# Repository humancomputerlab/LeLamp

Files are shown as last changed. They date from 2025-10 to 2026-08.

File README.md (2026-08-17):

# LeLamp

LeLamp Banner

An open source robot lamp based on [Apple's Elegnt](https://machinelearning.apple.com/research/elegnt-expressive-functional-movement), made by [Human Computer Lab](https://www.humancomputerlab.com/)

**UPDATE:** We are working on a closed-source version that will release end of 2027. You can also follow along on [TikTok](https://www.tiktok.com/@itslelamp?lang=en), [Instagram] (https://www.instagram.com/itslelamp/), [YouTube](https://www.youtube.com/@itslelamp), [LinkedIn](https://www.linkedin.com/company/humancomputerlab/?viewAsMember=true) and [X](https://x.com/humancomplab) for behind-the-scenes + updates.

[LeLamp Website](https://www.lelamp.com/)

## Overview

LeLamp in real life

**Build specs:** ~$260 cost | 8-12 hours | Intermediate skill level

LeLamp is an expressive robot lamp featuring:

- 🎭 **5-axis articulated movement** with servo motors
- 📸 **Computer vision** via Pi Camera
- 🎤 **Audio interaction** with microphone and speaker
- 💡 **LED expressions** with 24 programmable LEDs
- 🎮 **Record & replay** custom movements

## Build Guide

**Start here:** [Prerequisites & Planning](./docs/0.%20Prerequisites.md)

### Complete Build Process

1. [📋 Prerequisites & Planning](./docs/0.%20Prerequisites.md) - Skills, tools, and BOM
2. [🔧 Components & 3D Parts](./docs/1.%203D%20Print.md) - Components and 3D Printed Models
3. [🎯 Lamp Assembly](./docs/3.%20LeLamp%20Assembly.md) - Mechanical and electrical assembly
4. [🏗️ Lamp Setup](./docs/4.%20LeLamp%20Setup.md) - Runtime Setup
5. [🎮 Lamp Control](./docs/5.%20LeLamp%20Control.md) - Controlling LeLamp
6. [🔍 Common Issues](./docs/6.%20Common%20Issues.md) - Common issues and solutions

### Quick Reference

- **Bill of Materials**: [Complete component list with suppliers](./docs/0.%20Prerequisites.md#bill-of-materials)
- **3D Print Files**: Available in `/3D/` directory ([OnShape CAD](https://cad.onshape.com/documents/16c9706360b5ad34f9c8db49/w/2edfa54c83253c120fbc9e58/e/a7196194821d9cfe2842a44a))
- **Order the Kit**: [Register interest here](https://docs.google.com/forms/d/e/1FAIpQLSfOXO2q_I2LKqYE0LoPN8VtrpKWrvJ1OkRAiS1iBFML1eqoGw/viewform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)
- **Software Control**: [LeLamp Runtime Repository](https://github.com/humancomputerlab/lelamp_runtime)

## Project Status

⚠️ **Early Development** - This project is actively being developed. We published our progress early to encourage community feedback and iteration. We are working on a closed-source version that will release in 2026. You can also follow along on TikTok, Instagram, YouTube, LinkedIn and X for behind-the-scenes + updates.

## Community & Support

### Getting Help

- **Start here**: [Troubleshooting Guide](./docs/6.%20Troubleshooting.md) for common issues
- **Discord**: [Join our community](https://discord.gg/727JXBt8Zt) for real-time help and discussions
- **GitHub Issues**: [Report bugs or ask questions](https://github.com/humancomputerlab/le_lamp/issues)

### Contributing

We welcome contributions:

- 🐛 Bug reports and fixes
- 📖 Documentation improvements
- 🔧 Design enhancements
- 🌍 Regional supplier information
- 📸 Build photos and videos

Please check existing issues before creating new ones.

## Maintainers
Maintained by [Human Computer Lab](https://www.humancomputerlab.com).

## Acknowledgments & Sponsors
See [CONTRIBUTORS.md](./CONTRIBUTORS.md) for contributors and their roles.  
See [SPONSORS.md](./SPONSORS.md) for sponsor thanks and how to support the project.

## License

This project is licensed under the GNU General Public License v3.0 - see the [LICENSE](LICENSE) file for details.

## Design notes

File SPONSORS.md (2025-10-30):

Biggest thanks to Jennie and Lily at Seeed Studio for sponsoring the SO-101 Arm Kit for early developments of LeLamp.

Buy an SO-101 Arm Kit today on [SeeedStudio](https://www.seeedstudio.com/SO-ARM101-Low-Cost-AI-Arm-Kit-p-6426.html).

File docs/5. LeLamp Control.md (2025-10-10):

# Lamp Control

**⏱️ Estimated time:** 30 minutes  
**🔧 Required tools:** Computer with LeLamp runtime  
**📦 Required:** Fully assembled LeLamp with working head and body

For complete lamp control documentation, refer to the [**LeLamp Runtime's GitHub**](https://github.com/humancomputerlab/lelamp_runtime).

To follow this tutorial, ssh into your LeLamp and cd into `lelamp_runtime`. This was covered in the previous tutorial.

In commands below, remember to replace the name after `--id` to be your lamp name that you have used in previous section.

## Calibration

Before recording and replaying movements on the lamp, you need to calibrate:

```bash
sudo uv run -m lelamp.calibrate --id your_lamp_name --port your_port
```

The calibration script will run calibration twice, once for the lamp as a follower and once for the lamp as the leader. Follow the step outlined inside the CLI.

The script will mention you to put LeLamp into its zero position. The zero position is can be view in 3D [here](https://cad.onshape.com/documents/16c9706360b5ad34f9c8db49/w/2edfa54c83253c120fbc9e58/e/9bd935d578a9cbc77b5d66b3).

After putting LeLamp into its zero position, rotate each joint fully except for the lamp base motor (first motor on the base) or the lamp head motor (second motor from lamp head). **⚠️ Important: Do not fully rotate the lamp base or lamp head during calibration — this applies specifically to the two yaw servos. When setting them to their zero position, only rotate each servo about 90° clockwise and 90° counterclockwise from the center position. Rotating beyond this range may damage the servos or misalign the calibration.**

## Record and replay movements

To record movement, run the following command in runtime:

```bash
sudo uv run -m lelamp.record --id your_lamp_name --port your_port --name rotation
```

While recording movement, you can end and save the recording by holding `CTRL + C`.

To replay movement, run the following command in runtime:

```bash
sudo uv run -m lelamp.replay --id your_lamp_name --port your_port --name rotation
```

To list all recorded movements, run the following command in runtime:

```bash
sudo uv run -m lelamp.list_recordings --id your_lamp_name
```

## Final System Testing

After completing your LeLamp build, perform these final tests:

### Full System Integration Test

```bash
# Test all servo movements
sudo uv run -m lelamp.test.test_motors --id your_lamp_name --port your_port

# Test head components
sudo uv run -m lelamp.test.test_rgb     # LED ring
uv run -m lelamp.test.test_audio        # Audio I/O
libcamera-hello --timeout 2000         # Camera
```

### Record Your First Movement

1. **Position LeLamp** in a safe working area with full range of motion
2. **Record a simple movement** to test the system
3. **Replay the movement** to verify accuracy
4. **Save successful recordings** for future use

## Congratulations! 🎉

You have successfully built your LeLamp! Your robot lamp should now be capable of:

- ✅ Expressive movement through 5 degrees of freedom
- ✅ Visual interaction via camera
- ✅ Audio input/output for voice interaction
- ✅ Programmable LED expressions
- ✅ Recording and replaying custom movements

## Next Steps

- **Explore the runtime**: Check out advanced features in the [LeLamp Runtime repository](https://github.com/humancomputerlab/lelamp_runtime)
- **Join the community**: Share your build on [Discord](https://discord.gg/4hmNW3Ep)
- **Contribute back**: Help improve documentation or share build photos
- **Report issues**: Use [GitHub Issues](https://github.com/humancomputerlab/le_lamp/issues) for bugs or suggestions

---

**Previous**: [LeLamp Setup](./4.%20LeLamp%20Setup.md) | **Troubleshooting**: [Common Issues](./6.%20Common%20Issues.md)

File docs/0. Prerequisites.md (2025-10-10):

# Prerequisites for Building LeLamp

Before starting your LeLamp build, ensure you have the necessary skills, tools, and time to complete this project successfully.

## Skill Level Requirements

**Intermediate to Advanced** - This project requires:

- **Electronics experience**: Soldering, basic circuit understanding, component identification
- **3D printing knowledge**: Printer operation, material selection, post-processing
- **Software comfort**: Command line usage, SSH, basic Linux administration
- **Mechanical assembly**: Precision work with small components, heat inserts, servo mounting

**Estimated build time**: 8-12 hours over 2-3 days

## Required Tools

### Electronics Tools

- Soldering iron (temperature controlled, 15-25W)
- Solder (60/40 rosin core, 0.6-0.8mm)
- Wire strippers
- Small screwdrivers (Phillips #0, #1, flathead 2-3mm)
- Multimeter for continuity testing
- Anti-static wrist strap (recommended)

### Mechanical Tools

- Heat insert soldering iron tip OR dedicated heat insert tool
- M2 and M3 Allen keys/hex drivers
- Small pliers (needle nose)
- Wire cutters/flush cutters
- Digital calipers (for verification)

### 3D Printing Requirements

- **Printer bed size**: Minimum 200x200x150mm
- **Materials**: PLA+ recommended (PETG acceptable)
- **Layer height**: 0.2mm standard, 0.15mm for critical parts
- **Infill**: 20% minimum, 30% for structural components
- **Supports**: Required for some parts (see individual STL notes)

## Safety Warnings

⚠️ **ELECTRICAL SAFETY**

- Always disconnect power when making connections
- Use proper ESD precautions when handling Pi and servo driver
- Main power supply is 5V - verify correct voltage before connection
- Double-check polarity before powering on

⚠️ **MECHANICAL SAFETY**

- Heat inserts reach 200°C+ - use appropriate tools
- Servo horns under tension can snap - wear eye protection
- Small parts present choking hazard

## Bill of Materials

Bill of materials for LeLamp can be found [here](https://docs.google.com/spreadsheets/d/1C50qqSxJjCHEnh6j_Dcfx8JzyLlGobKSOYA0ePJUDVk/edit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).

Note: The links inside the BOM are reference only. You don't need to buy from those links. You should find the best deals in your region if possible.

**Total estimated cost (United States): $310.64 USD**

## Required External Resources

Before starting, ensure you have access to:

- **3D Printer** or printing service
- **Computer** for Pi setup and servo configuration
- **WiFi network** for Pi connectivity
- **LeLamp Runtime Repository**: https://github.com/humancomputerlab/lelamp_runtime

## Time Planning

### Phase 1: Preparation (2-3 hours)

- Download and review all documentation
- Source all components
- 3D print all parts
- Set up software environment

### Phase 2: Electronics Prep (2-3 hours)

- Test all components individually
- Solder headers and connectors
- Set up Raspberry Pi OS
- Configure servo IDs

### Phase 3: Assembly (4-6 hours)

- Install heat inserts
- Mount servos in 3D printed parts
- Route wiring through body
- Assemble head components
- Final integration and testing

## Pre-Build Checklist

- [ ] All components sourced and verified working
- [ ] 3D parts printed and post-processed
- [ ] Tools and workspace prepared
- [ ] Software downloaded and accounts created
- [ ] Safety equipment ready
- [ ] Adequate time allocated (don't rush!)

## Getting Help

If you encounter issues:

- **Discord Community**: https://discord.gg/4hmNW3Ep
- **GitHub Issues**: Report bugs and ask questions
- **Documentation**: Always check troubleshooting section first

---

**Next Step**: [1. 3D Print LeLamp](./1.%203D%20Print.md)

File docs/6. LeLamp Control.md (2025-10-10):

# Lamp Control

**⏱️ Estimated time:** 30 minutes  
**🔧 Required tools:** Computer with LeLamp runtime  
**📦 Required:** Fully assembled LeLamp with working head and body

For complete lamp control documentation, refer to the [**LeLamp Runtime's GitHub**](https://github.com/humancomputerlab/lelamp_runtime).

To follow this tutorial, ssh into your LeLamp and cd into `lelamp_runtime`. This was covered in the previous tutorial

## Calibration

Before recording and replaying movements on the lamp, you need to calibrate:

```bash
sudo uv run -m lelamp.calibrate --id lelamp --port /dev/tty.usbmodem5A680114681
```

The calibration script will run calibration twice, once for the lamp as a follower and once for the lamp as the leader. Follow the step outlined inside the CLI.

The script will mention you to put LeLamp into its zero position. The zero position is can be view in 3D [here](https://cad.onshape.com/documents/16c9706360b5ad34f9c8db49/w/2edfa54c83253c120fbc9e58/e/9bd935d578a9cbc77b5d66b3).

After putting LeLamp into its zero position, rotate each joint fully except for the lamp base motor (first motor on the base) or the lamp head motor (second motor from lamp head). **⚠️ Important: Do not fully rotate the lamp base or lamp head during calibration — this applies specifically to the two yaw servos. When setting them to their zero position, only rotate each servo about 90° clockwise and 90° counterclockwise from the center position. Rotating beyond this range may damage the servos or misalign the calibration.**

## Record and replay movements

To record movement, run the following command in runtime:

```bash
sudo uv run -m lelamp.record --id lelamp --port /dev/tty.usbmodem5A680114681 --name rotation
```

While recording movement, you can end and save the recording by holding `CTRL + C`.

To replay movement, run the following command in runtime:

```bash
sudo uv run -m lelamp.replay --id lelamp --port /dev/tty.usbmodem5A680114681 --name rotation
```

To list all recorded movements, run the following command in runtime:

```bash
sudo uv run -m lelamp.list_recordings --id lelamp
```

## Final System Testing

After completing your LeLamp build, perform these final tests:

### Full System Integration Test

```bash
# Test all servo movements
sudo uv run -m lelamp.test.test_motors --id lelamp --port /dev/ttyUSB0

# Test head components
sudo uv run -m lelamp.test.test_rgb     # LED ring
uv run -m lelamp.test.test_audio        # Audio I/O
libcamera-hello --timeout 2000         # Camera
```

### Record Your First Movement

1. **Position LeLamp** in a safe working area with full range of motion
2. **Record a simple movement** to test the system
3. **Replay the movement** to verify accuracy
4. **Save successful recordings** for future use

## Congratulations! 🎉

You have successfully built your LeLamp! Your robot lamp should now be capable of:

- ✅ Expressive movement through 5 degrees of freedom
- ✅ Visual interaction via camera
- ✅ Audio input/output for voice interaction
- ✅ Programmable LED expressions
- ✅ Recording and replaying custom movements

## Next Steps

- **Explore the runtime**: Check out advanced features in the [LeLamp Runtime repository](https://github.com/humancomputerlab/lelamp_runtime)
- **Join the community**: Share your build on [Discord](https://discord.gg/4hmNW3Ep)
- **Contribute back**: Help improve documentation or share build photos
- **Report issues**: Use [GitHub Issues](https://github.com/humancomputerlab/le_lamp/issues) for bugs or suggestions

---

**Previous**: [LeLamp Setup](./5.%20LeLamp%20Setup.md) | **Troubleshooting**: [Common Issues](./7.%20Common%20Issues.md)

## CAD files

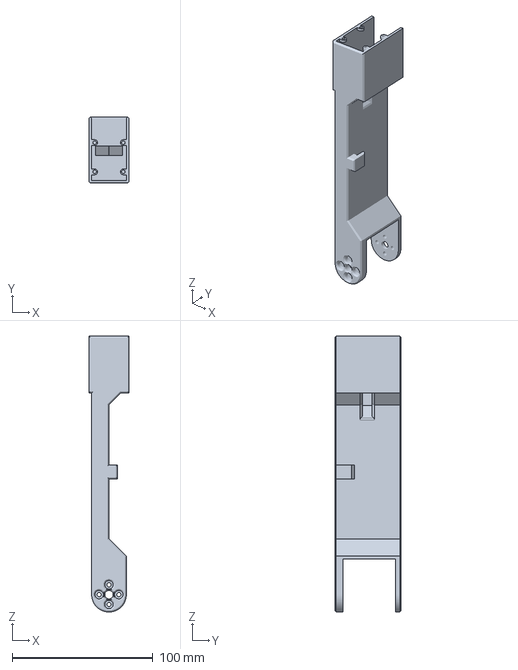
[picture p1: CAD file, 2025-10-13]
3D/LampArm (Elbow-Wrist).3mf
28.7 x 47.2 x 196.3 mm

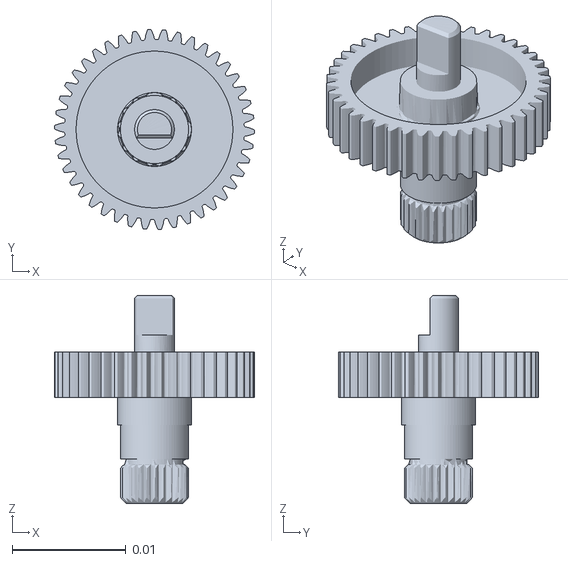
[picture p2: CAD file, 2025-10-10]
simulation/assets/ge_27.stl
0.0176 x 0.0176 x 0.0183

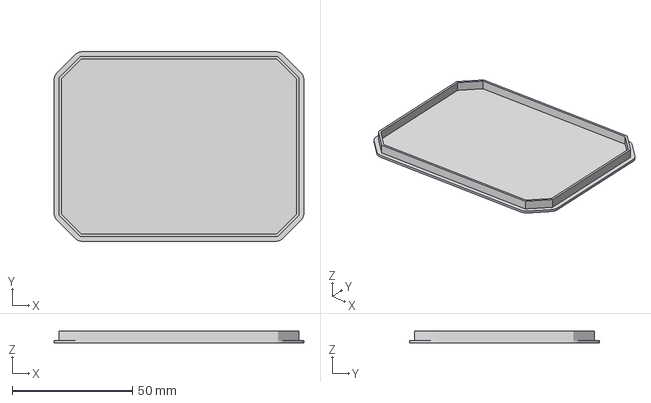
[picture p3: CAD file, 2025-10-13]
3D/LampHead - Diffuser.3mf
104.0 x 79.0 x 5.00 mm

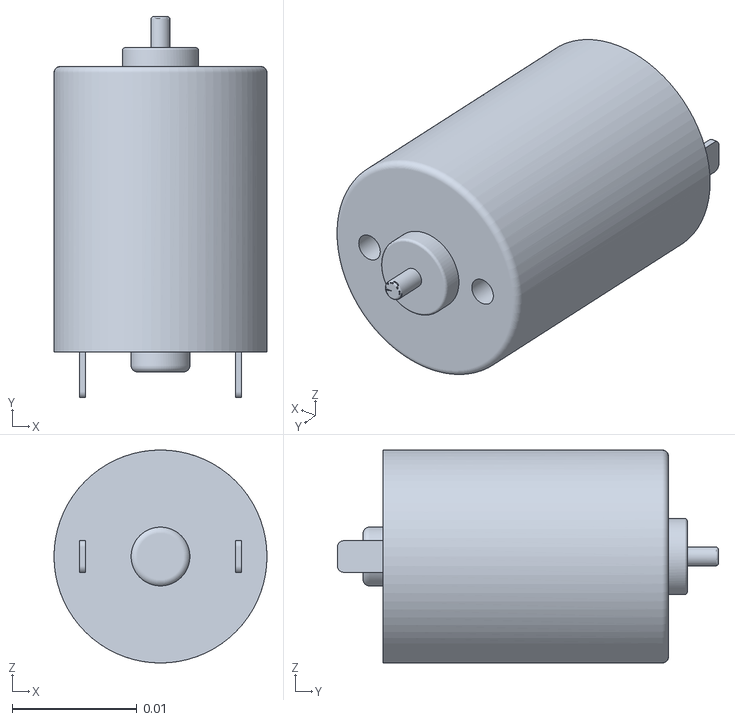
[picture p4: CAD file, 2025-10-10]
simulation/assets/motor_1723_3.stl
0.017 x 0.0305 x 0.017

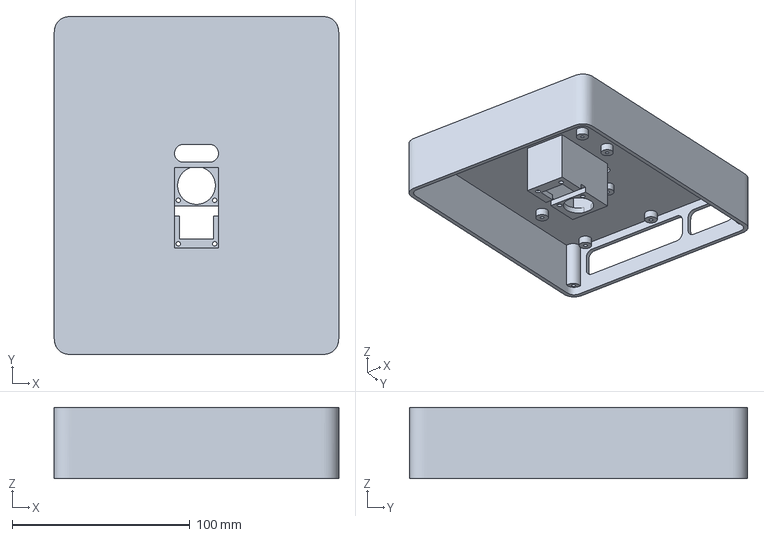
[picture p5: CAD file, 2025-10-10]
3D/LampBase.3mf
160.0 x 190.0 x 40.0 mm

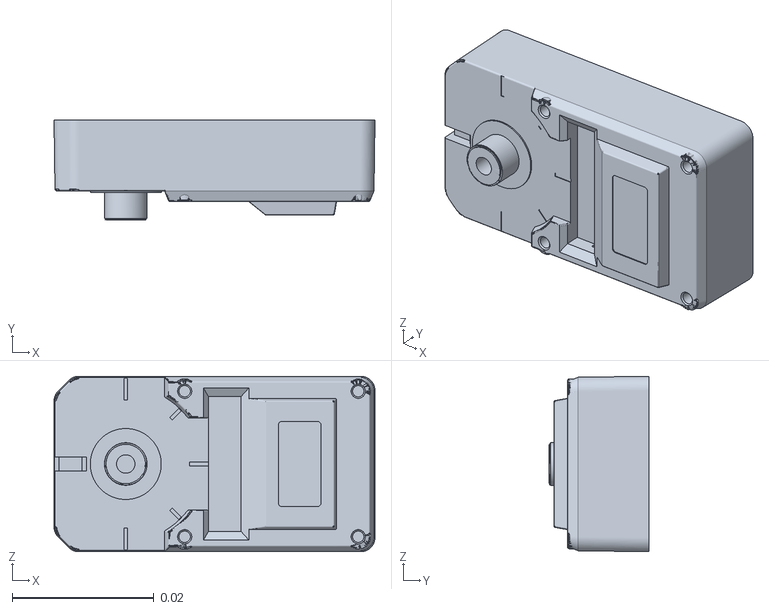
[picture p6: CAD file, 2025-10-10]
simulation/assets/xg_ziji_16.stl
0.0452 x 0.0141 x 0.0247

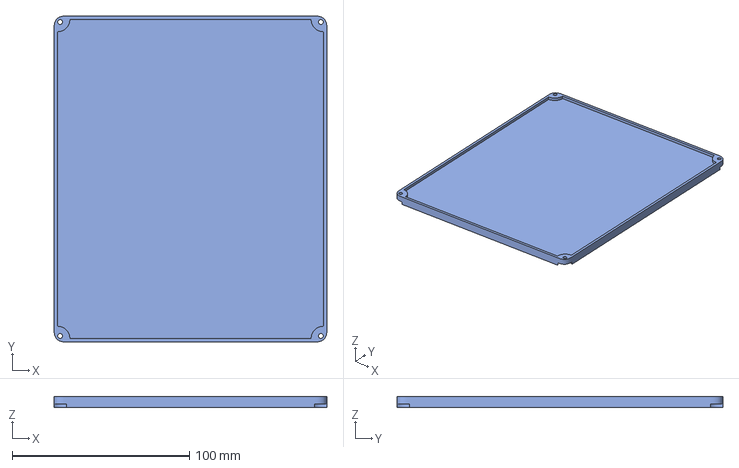
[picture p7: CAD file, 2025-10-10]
3D/LampBase - Cover.3mf
153.8 x 183.8 x 6.00 mm

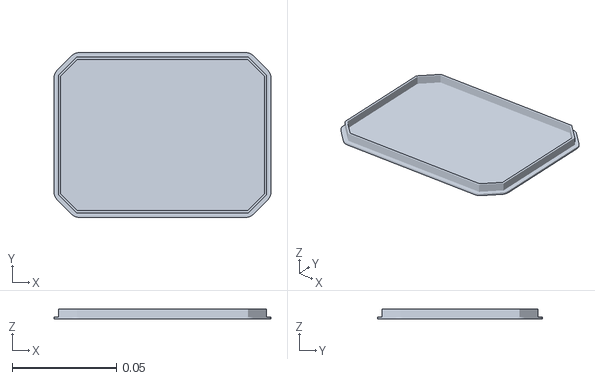
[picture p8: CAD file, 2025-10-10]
simulation/assets/diffuser.stl
0.104 x 0.079 x 0.005

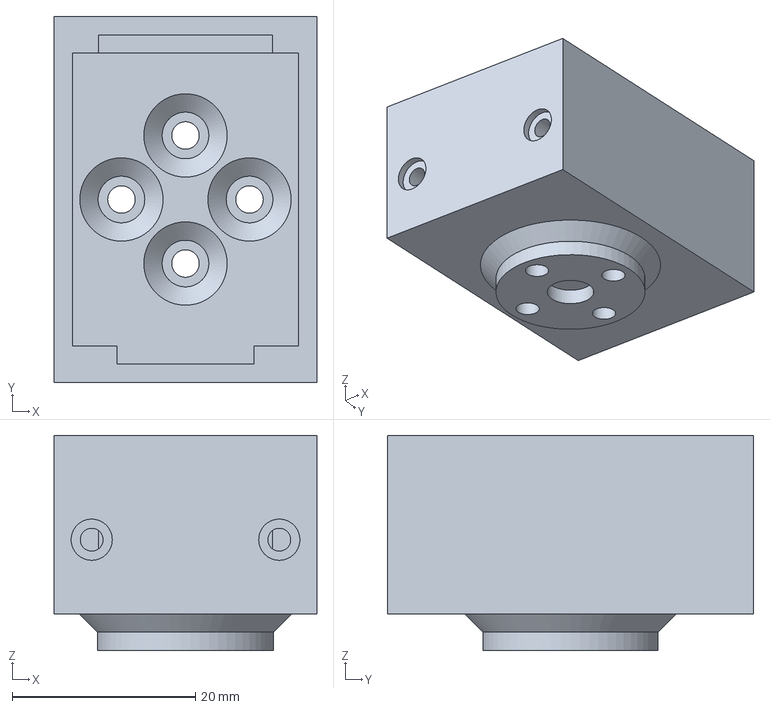
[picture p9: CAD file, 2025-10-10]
3D/LampArm (Pitch).3mf
28.7 x 40.0 x 23.5 mm

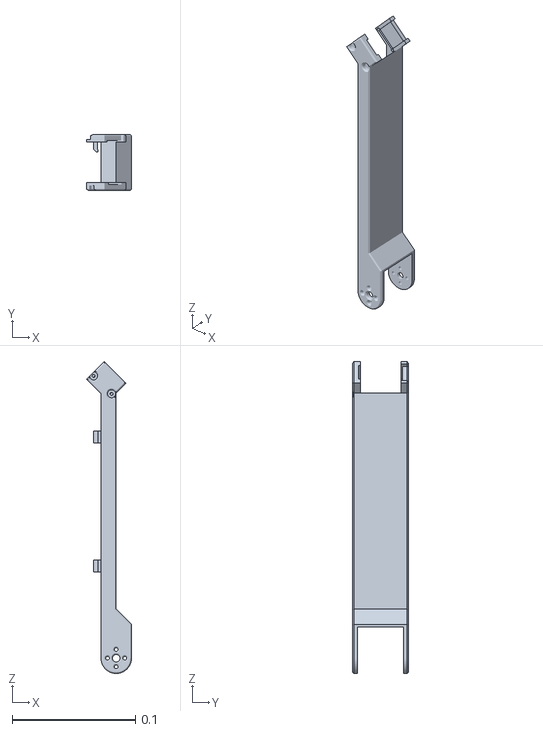
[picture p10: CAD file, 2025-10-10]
simulation/assets/lamparm__base_elbow.stl
0.0364 x 0.0452 x 0.253

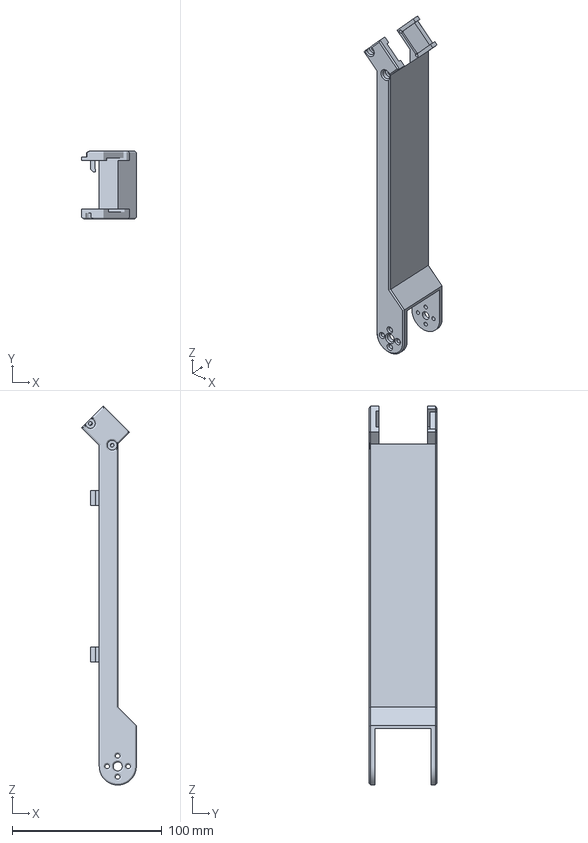
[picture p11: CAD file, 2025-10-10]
3D/LampArm (Base-Elbow).3mf
36.4 x 45.2 x 252.7 mm

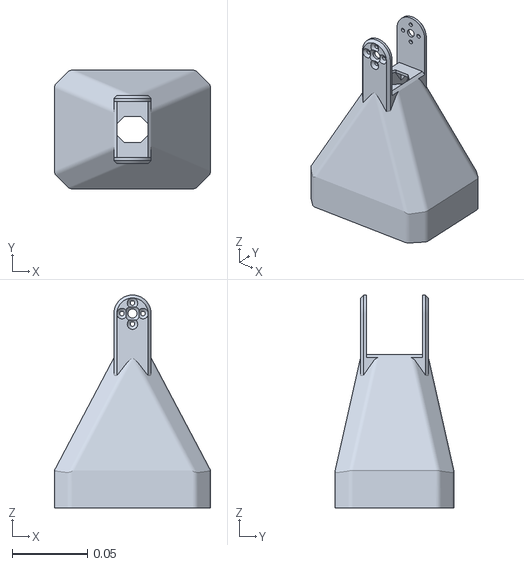
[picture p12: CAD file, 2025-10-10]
simulation/assets/lamphead.stl
0.104 x 0.079 x 0.142

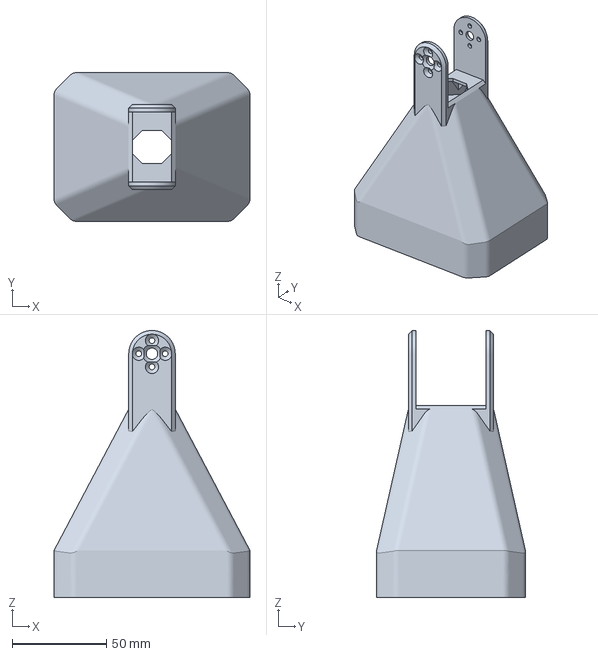
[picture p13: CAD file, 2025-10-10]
3D/LampHead.3mf
104.0 x 79.0 x 141.7 mm

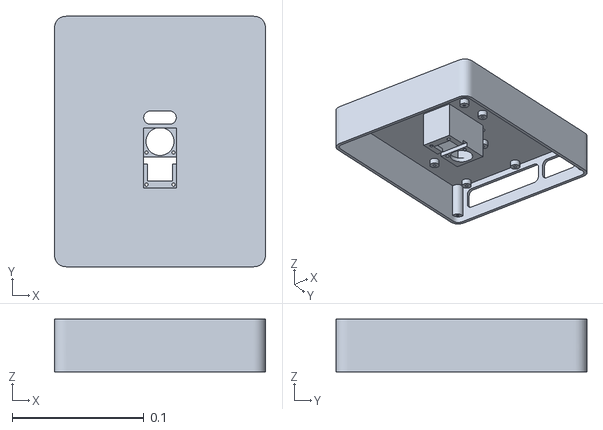
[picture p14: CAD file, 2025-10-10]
simulation/assets/lamp_base.stl
0.16 x 0.19 x 0.04

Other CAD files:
simulation/assets/sg_ziji_15.stl
simulation/assets/lamp_base_cover.stl
simulation/assets/lamparm__elbow_wrist.stl

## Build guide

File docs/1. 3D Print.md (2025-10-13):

# 3D Print

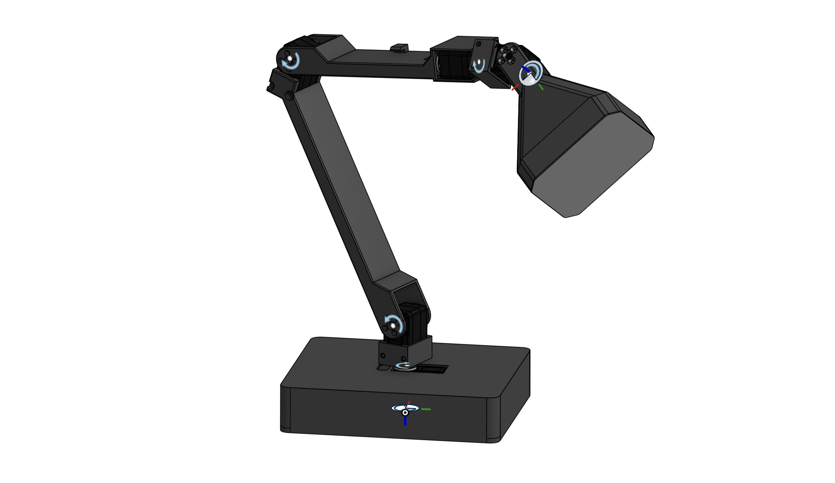
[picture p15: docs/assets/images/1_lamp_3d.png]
Lamp


You can find the .3mf files for 3D printed parts of LeLamp inside `/3D/`. You can also view it in [OnShape](https://cad.onshape.com/documents/16c9706360b5ad34f9c8db49/w/2edfa54c83253c120fbc9e58/e/a7196194821d9cfe2842a44a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).

To build your LeLamp, you need to print the following parts:

- **1x Lamp Base**: Contains servo driver and a normal pi.
- **1x Lamp Base Cover**: Cover lamp base.
- **1x LampArm (Base to Elbow)**: Contains base pitch and elbow pitch servo.
- **1x LampArm (Elbow to Wrist)**: Contains elbow pitch and wrist roll servo.
- **2x LampArm (Pitch)**: Contains base pitch or wrist pitch servo.
- **1x Lamp Head**: Contains led matrix and speaker.
- **1x Lamp Head - Diffuser**: Diffuse LED Matrix.

## Print Orientation And Settings

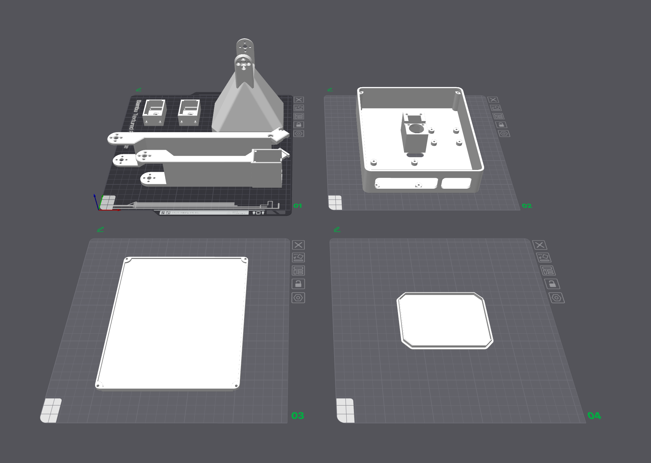
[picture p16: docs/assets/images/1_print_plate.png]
Print Plate


For the optimal print orientation and order, you can reference the following image.

For optimal print setting, you can follow the default setting of your preferred printer. Here are some general notes:

- **Filament**: PLA
- **Layer Height**: 0.2mm
- **Infill Density**: 15%
- **Enabled Support**: Yes
- **Support Type**: Tree type

---

**Previous**: [Prerequesites](./0.%20Prerequisites.md) | **Next**: [Electronics](./2.%20Electronics.md)

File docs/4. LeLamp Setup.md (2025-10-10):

# 🛠️ LeLamp Runtime Setup Guide

**⏱️ Estimated time:** 1–2 hours
**🔧 Required tools:** Computer, USB cable, SD Card Reader
**📦 Required components:** Raspberry Pi, SD Card

## 1. OS

Using [Pi Imager](https://www.raspberrypi.com/software/), flash **Raspberry Pi OS Lite (64-bit)** onto your Raspberry Pi. You can reference how to do this [here](https://www.raspberrypi.com/documentation/computers/getting-started.html).

In this tutorial, we used the Debian Bookworm version (released 2025-05-13).

When prompted to configure the settings on your pi, remember to:

- Set the Wifi SSID and password.
- Set the username and password.
- Set the hostname
- Enable SSH

## 2. Runtime

**Important Note:** As a common practice, review the output of each command carefully after running. Do as you are instructed within each command and their output.

After successfully flashing your pi, SSH into it by running the following command:

```bash
ssh your_username@your_host_name.local
```

Then you need to set up [LeLamp Runtime](https://github.com/humancomputerlab/lelamp_runtime):

```bash
git clone https://github.com/humancomputerlab/lelamp_runtime.git
```

To use LeLamp's runtime, install uv:

```bash
curl -LsSf https://astral.sh/uv/install.sh | sh
```

Install the necessary dependencies for audio:

```bash
sudo apt-get install portaudio19-dev
```

To setup the runtime:

```bash
cd lelamp_runtime
uv sync --extra hardware
```

This will take a while.

## 3. Setup Mic and Speaker

If you use the ReSpeaker Hat for Raspberry Pi, you can reference their tutorial [here](https://wiki.seeedstudio.com/respeaker_2_mics_pi_hat_raspberry_v2/).

For convenience, the tutorial is below:

1. Get Device Tree Source (DTS) for the ReSpeaker 2-Mics Pi HAT (V2.0), compile it and install the device tree overlay.

   ```bash
   curl https://raw.githubusercontent.com/Seeed-Studio/seeed-linux-dtoverlays/refs/heads/master/overlays/rpi/respeaker-2mic-v2_0-overlay.dts -o respeaker-2mic-v2_0-overlay.dts
   dtc -I dts respeaker-2mic-v2_0-overlay.dts -o respeaker-2mic-v2_0-overlay.dtbo
   sudo dtoverlay respeaker-2mic-v2_0-overlay.dtbo
   sudo cp respeaker-2mic-v2_0-overlay.dtbo /boot/firmware/overlays
   ```

2. Edit /boot/firmware/config.txt:

   ```bash
   sudo tee -a /boot/firmware/config.txt >/dev/null <<'EOF'
   dtoverlay=respeaker-2mic-v2_0-overlay
   dtoverlay=i2s-mmap
   EOF
   ```

3. Edit sudo's sound config:

```bash
sudo tee /etc/asound.conf > /dev/null <<'EOF'
# Default capture & playback device = Seeed 2-Mic
pcm.!default {
    type plug
    slave {
        pcm "hw:3,0"      # input/output device (Seeed 2-Mic)
    }
}

ctl.!default {
    type hw
    card 3
}
EOF
```

4. Reboot your device:

   ```bash
   sudo reboot
   ```

5. Check if your device is enabled:

   ```bash
   aplay -l
   ```

   The expected output should be like this:

   ```bash
   card 2: seeed2micvoicec [seeed2micvoicec], device 0: 1f000a4000.i2s-tlv320aic3x-hifi tlv320aic3x-hifi-0 [1f000a4000.i2s-tlv320aic3x-hifi tlv320aic3x-hifi-0]
   Subdevices: 1/1
   Subdevice #0: subdevice #0
   ```

   Afterwards, you can set up the sound level with the following command:

   ```bash
   alsamixer
   ```

   Inside alsamixer, you can F6 to select device `seeed2micvoicec`. The audio setting to be edited is `Line`, `Line DAC`, `PCM`. This audio setting can be muted by default, which you can unmute by typing `M` when selecting `Line`. You should set the volume level to 100 on the first try.

## 4. Test functionalities

### RGB

For RGB, run the following command with sudo:

```bash
sudo uv run -m lelamp.test.test_rgb
```

In case you can't find uv as root, run:

```bash
which uv
```

Then replace uv with the output, for example:

```bash
sudo /home/pi/.local/bin/uv run -m lelamp.test.test_rgb
```

If you don't want to do this long path every single time, you can add the path to uv to sudo's secure path:

```bash
sudo visudo
```

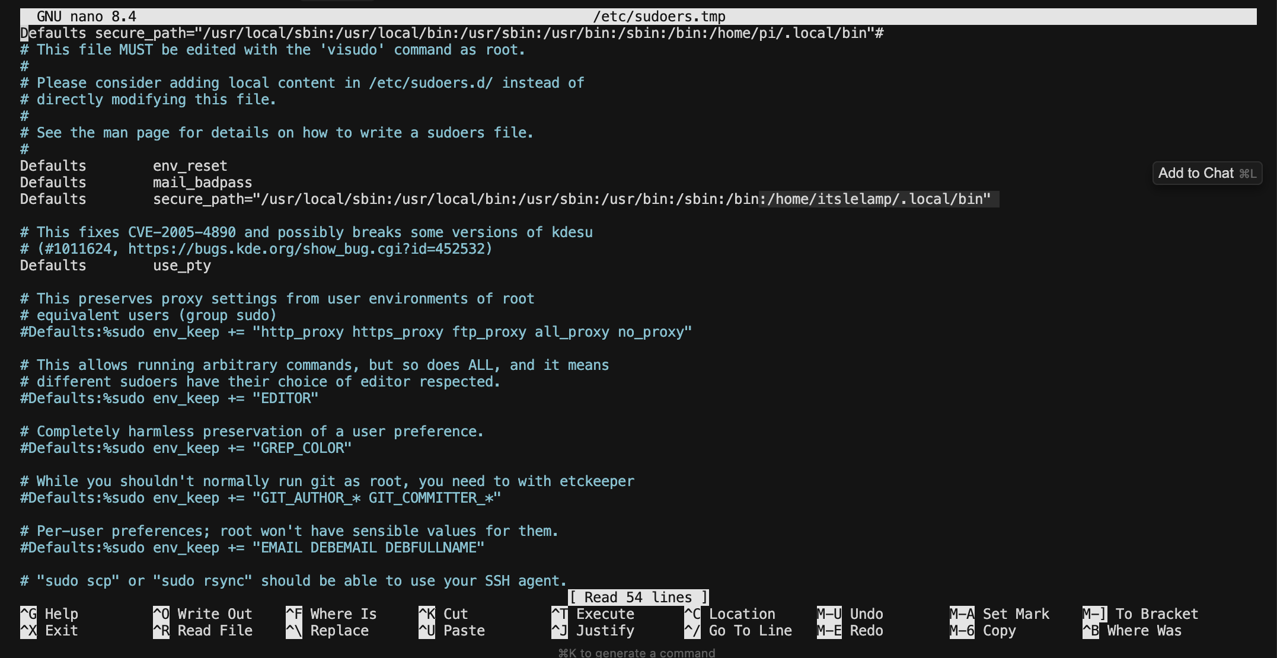
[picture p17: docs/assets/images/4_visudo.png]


Add the following `/home/pi/.local/bin` (Remember to change your username):

```bash
Defaults secure_path="/usr/local/sbin:/usr/local/bin:/usr/sbin:/usr/bin:/sbin:/bin:/home/<your_user_name_here>/.local/bin"
```

### Mic and Speaker

For Mic and Speaker, run the following command:

```bash
uv run -m lelamp.test.test_audio
```

### Servo

Connect Pi to the servo driver through the USB port, then run the following to find which port the servo is connected to:

```bash
uv run lerobot-find-port
```

You need to unplug your USB during this process to find which port the servo is connected to. Most likely it is `/dev/ttyACM0`.

Then run the following command to check whether the servos are available:

```bash
uv run -m lelamp.test.test_motors --id your_lamp_name --port port_your_servo_driver_is_connected_to
```

## Assembly Completion Checklist

After completing lamp setup, verify:

- [ ] All the above test pass

## What You Should Have

At this stage, you should have:

- **A functional LeLamp**.

---

**Previous**: [LeLamp Assembly](./3.%20LeLamp%20Assembly.md) | **Next**: [LeLamp Control](./5.%20LeLamp%20Control.md)

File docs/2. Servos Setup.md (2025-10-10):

# Servo Setup

**⏱️ Estimated time:** 30-45 minutes  
**🔧 Required tools:** Computer, servo driver, USB cable  
**📦 Required components:** 5x STS3215 servos, servo driver board

The first part of assembling LeLamp is setting up your servos.

## 0. Download LeLamp Runtime on your computer

On your personal computer, using the CLI terminal of your choice, clone the [LeLamp's Runtime Repository](https://github.com/humancomputerlab/lelamp_runtime):

```sh
git clone https://github.com/humancomputerlab/lelamp_runtime
cd lelamp_runtime
```

Install uv:

```bash
curl -LsSf https://astral.sh/uv/install.sh | sh
```

Then setup the runtime by:

```bash
uv sync
```

In later part of this tutorial, you will have to setup LeLamp's runtime again, but on your Raspberry Pi.

## 1. Unbox and lay your servos on a table.

Servos on table

## 2. Label your servos.

Label your servos.

| Servo Name  | Servo ID |
| --- | --- |
| base_yaw | 1 |
| base_pitch  | 2 |
| elbow_pitch | 3 |
| wrist_roll  | 4 |
| wrist_pitch | 5 |

Based on the table above, you should label your servo accordingly. There's no particular order to this or specific servo you should label with a certain ID.

The end result is having 5 servos, each with a label that tells you which is which.

## 3. Run LeLamp's motor setup script.

This step should be done on your personal computer or laptop.

Run LeLamp's motor setup script

Connect the servo driver to your computer and figure which port it is connected to.

Inside `lelamp_runtime`, you can find port this by running:

```bash
uv run lerobot-find-port
```

For motor setup, inside `lelamp_runtime`, run the following command and connect the servo accordingly:

```bash
uv run -m lelamp.setup_motors --id your_lamp_name --port port_your_servo_driver_is_connected_to
```

Example:

```bash
uv run -m lelamp.setup_motors --id lelamp --port /dev/tty.usbmodem5A680114681
```

Remember the name you set for your lamp, you will use it again in the future.

## Success Criteria

After completing servo setup, you should have:

- [ ] 5 servos labeled with their intended positions
- [ ] All servos responding correctly to commands
- [ ] Servo IDs properly configured (1-5)
- [ ] Motor setup script completed successfully

## Troubleshooting

**Common issues:**

- **Servo not detected**: Check USB connection and port
- **Permission errors**: May need `sudo` or add user to dialout group
- **Servo ID conflicts**: Ensure each servo has unique ID

---

**Previous**: [3D Print](./1.%203D%20Print.md) | **Next**: [Lamp Assembly](./3.%20LeLamp%20Assembly.md.md)

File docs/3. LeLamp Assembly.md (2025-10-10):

# 🛠️ LeLamp Assembly Guide

**⏱️ Estimated time:** 1–2 hours
**🔧 Required tools:** Soldering iron, screwdrivers, heat insert tool  
**📦 Required components:** Raspberry Pi, ReSpeaker Hat, speaker, LED Matrix, SD card, servo driver

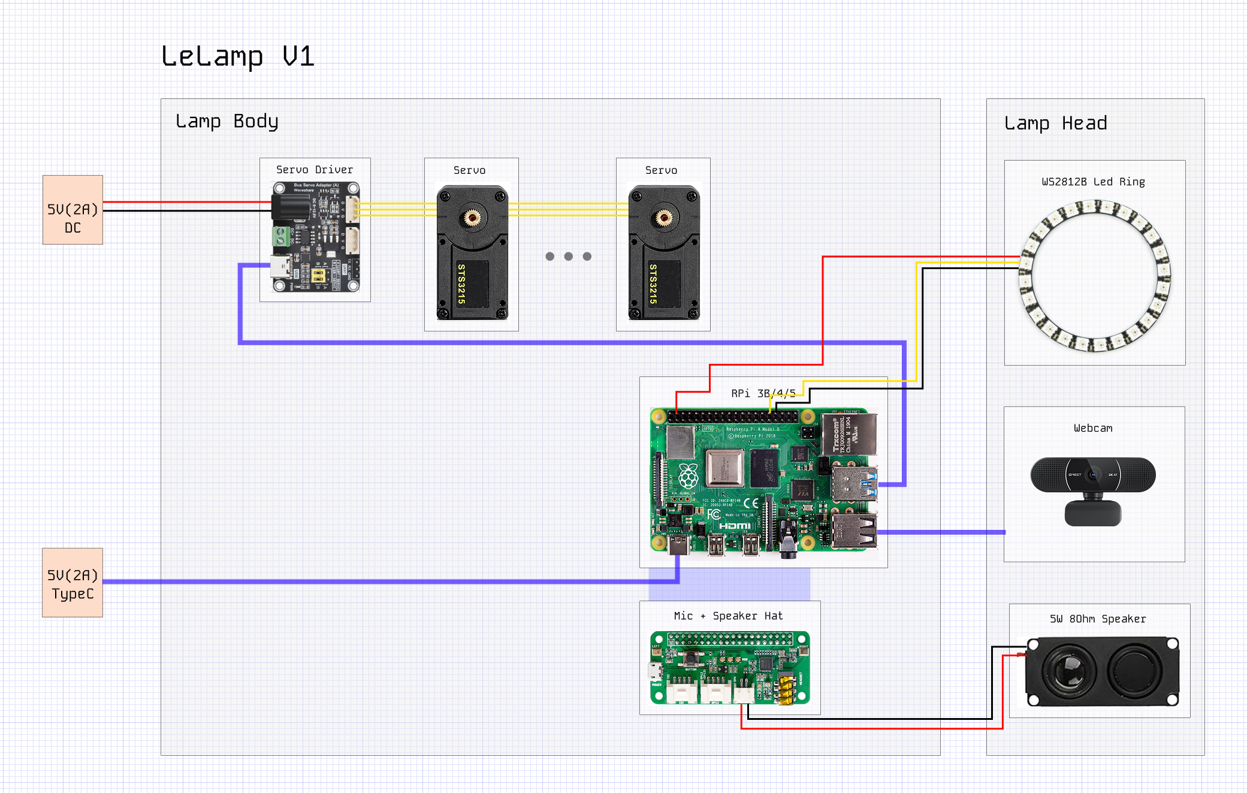
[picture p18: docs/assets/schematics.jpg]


## Overview

LeLamp consists of three main sections: the **Head**, the **Base**, and the **Body**, each containing essential functional components.

### LeLamp Head

- **Speaker** — 4 Ω / 3 W audio output
- **LED Matrix** — WS2812B programmable LEDs for expression

### LeLamp Base

- **Raspberry Pi with ReSpeaker Hat** — Controls servos, audio, and LEDs
- **Motor Driver** — Drives the servo motors

### LeLamp Body

- **Motors** - Actuators of the Lamp

All connections between the Head and Base are made through a **stripped Ethernet cable**, which carries power and data signals. Connections from the Base to motors are through the default wires given with each motor.

## Soldering and Assembly

### 1. Assembling the LeLamp Head

Use a **stripped Ethernet cable** to connect the speaker and LED matrix in the head to the base. The image below shows the general wiring layout:

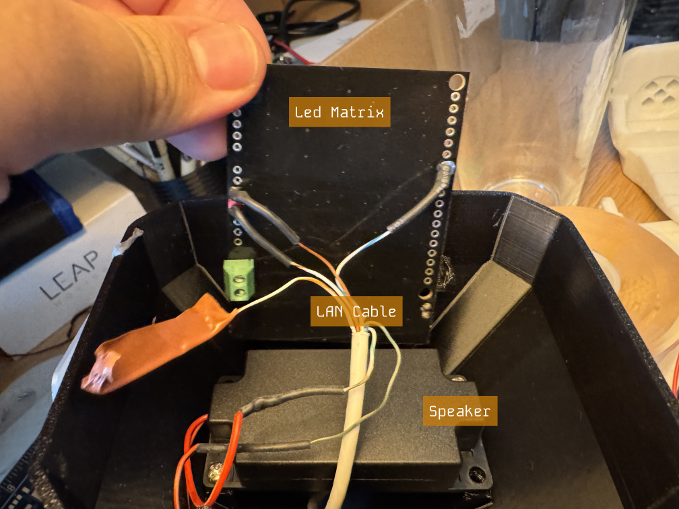
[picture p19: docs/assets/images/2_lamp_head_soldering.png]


1. **Prepare the Ethernet cable:** Strip the insulation to expose the individual wires.
2. **Solder connections:**
   - Solder each Ethernet wire to the pads of the **speaker** and **LED matrix**.
   - Keep track of which wire connects to which pad (e.g., GND, 5V, Data).
3. **Follow color conventions:**
   - **Black** — GND
   - **Red** — 5V
   - **Yellow** — Data
4. If you’re unfamiliar with WS2812B LED wiring, refer to this [tutorial](https://lastminuteengineers.com/ws2812b-arduino-tutorial/).
5. The image above also indicates the **orientation and placement** of the speaker and LED matrix inside the head.

> 💡 _Tip:_ You may also use individual wires instead of an Ethernet cable, as long as each wire is at least **50 cm** long to reach from the head to the base.

### 2. Assembling the LeLamp Base

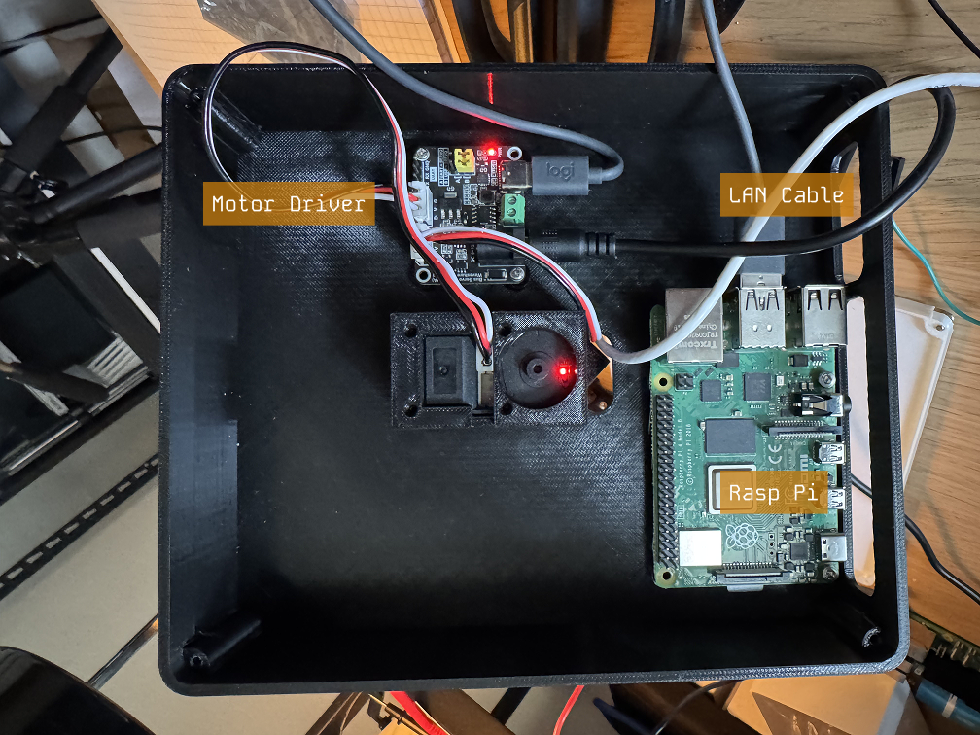
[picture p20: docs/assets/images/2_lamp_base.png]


1. **Mount the electronics:**
   - Secure the **motor driver board** and **Raspberry Pi** inside the base as shown above.
2. **Connect the boards:**

   - Use a **USB Type-C cable** to connect the motor driver to the Raspberry Pi.

3. **Prepare the ReSpeaker Hat:**

   - Solder the **header pins** on the ReSpeaker Hat as shown in the image.

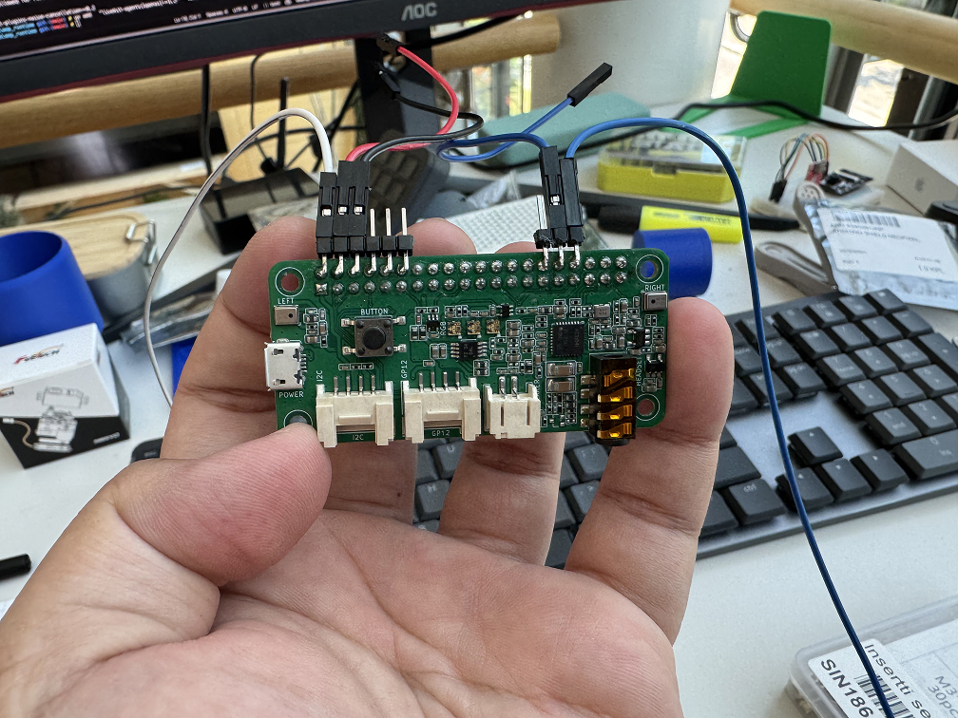
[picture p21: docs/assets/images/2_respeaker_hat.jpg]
   

4. **Connect the ReSpeaker Hat as shown in below image**
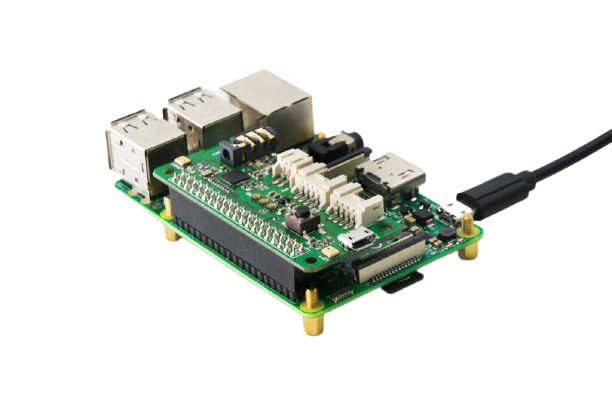
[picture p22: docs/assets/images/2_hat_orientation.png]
   
5. **Connect the head wiring:**
   - On the other end of the Ethernet cable (coming from the lamp head), solder **female header connectors** to each wire and **JST2.0 male** to the speaker wire.
   - Carefully match each wire to the corresponding pin on the ReSpeaker Hat, following the **schematics** for correct connections. You can connect the JST2.0 of speakers directly to the speaker port on the respeaker hat.

> ⚠️ _Reminder:_ Double-check all connections before powering on. Incorrect wiring can damage components.

### 3. Assembling LeLamp Body

The best way to assemble LeLamp Body is to reference the [OnShape's Assembly](https://cad.onshape.com/documents/16c9706360b5ad34f9c8db49/w/2edfa54c83253c120fbc9e58/e/a35eec618cd78ea5d74bf01b).

Using this 3D viewer, you can reference exactly the orientation and placement of each motor and part of the lamp.

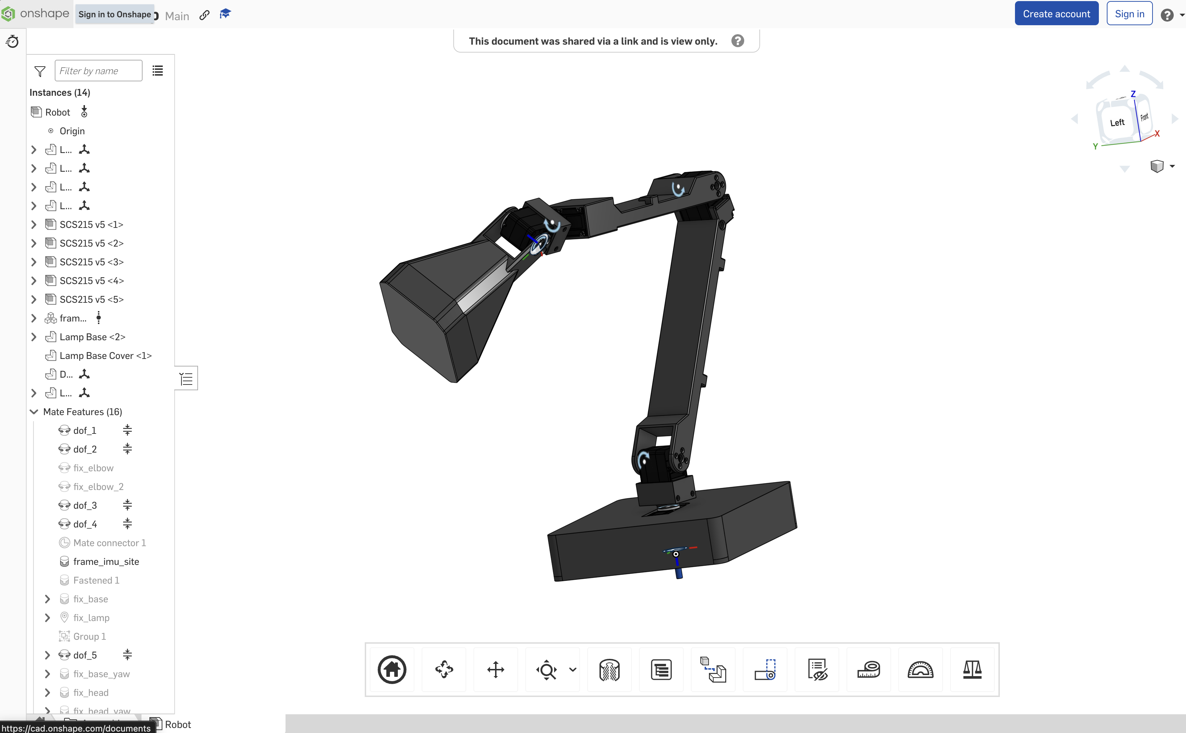
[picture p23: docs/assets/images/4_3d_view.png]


For convenience, the 2D view of motors can be found below.

**Please read through this whole section before you assemble the motors onto your Lamp**.

## Motor Assembly

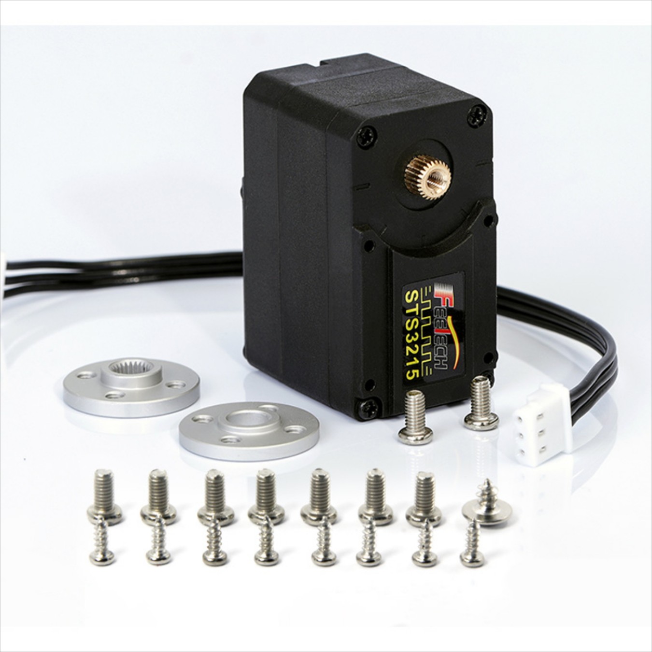
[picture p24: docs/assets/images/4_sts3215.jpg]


Each STS3215 servo motor comes with two motor horns — one with gears and one without. Before mounting the servos onto the lamp structure, first attach the geared horn to the motor’s output side (the side with the copper gear) and secure it firmly with screws. On the opposite side, place the non-geared horn; this one does not need to be screwed in, as it serves only for axis alignment.

Because the motor body is asymmetrical, the orientation of the motor horns is critical to ensure proper movement and reliability. Refer to the reference images below to confirm correct positioning.

### Motor Placement





### Motor Orientation



Use the side of the motor with the geared horn for installation. When viewing LeLamp from the top-down, with the wire slit on the base (or wire hole on newer versions) facing right, the pitch servo horns (the ones with gears) should be oriented outward, facing away from you—that is, toward the front of the lamp.



**For the yaw and roll servos, you don't need to attach the axis alignment horn.** Their orientation can be refereced in above image.

Again, if you are unsure, referece the 3D viewer from above.

### Motor Wiring

You should install all motors in their designated positions before wiring them. The motors are daisy-chained in sequence, starting from the Wrist Pitch Servo and ending at the Base Yaw Servo, which connects directly to the motor driver.

Refer to the schematics or the lamp base image above for proper wiring orientation and connection order.

> ⚠️ _Reminder:_ If your motor wire isn't long enough, you have to extend them through another wire by [splicing the wires](https://www.youtube.com/watch?v=r7GlDBge_WU).

## Power

You'll need 2 power supplies to power LeLamp:

1. **A 5V 2A DC Power Supply With DC Plug**: This is used to provide power to the servos.
2. **A 5V 2A Type C Charger**: This is used to provide power to the Rasperry Pi.

You can reduce the amount of power supply to 1 by providing the 5V from the motor driver to the pi. However, this is not recommended and has high risk of bricking your Pi.

## Assembly Completion Checklist

After completing lamp assembly, verify:

- [ ] All parts are connected
- [ ] An assembled LeLamp

## What You Should Have

At this stage, you should have:

- **Functional head assembly** with all electronics working
- **Proper cable management** with wires routed through head structure

---

**Previous**: [Servo Setup](./2.%20Servos%20Setup.md) | **Next**: [LeLamp Setup](./4.%20LeLamp%20Setup.md)

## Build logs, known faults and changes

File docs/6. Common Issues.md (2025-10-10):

# LeLamp Troubleshooting Guide

This guide covers common issues encountered during LeLamp assembly and operation, with step-by-step solutions.

## 1. Hardware Issues

### RGB Problems

**Problem**: The LED matrix doesn't light up fully.

- **Edit number of LEDs**: You can edit the number of LED used in lelamp_runtime: `/lelamp/service/rgb/rgb_service.py`. You can find led_count as an default parameter of RGBService Class. Change this to change the number of LEDs or change the number in any instantiation of this class.

### Pi Setup Problems

**Problem**: Cannot SSH into Pi

- **Check network connection**: Verify Pi is connected to WiFi
- **Verify SSH enabled**: Ensure SSH was enabled during OS setup
- **Check hostname**: Try IP address instead of hostname.local
- **Firewall issues**: Temporarily disable computer firewall for testing

**Problem**: Runtime installation fails

- **Check internet connection**: Ensure Pi has stable internet access
- **Update system**: Run `sudo apt update && sudo apt upgrade` first
- **Install uv manually**: Follow official uv installation instructions
- **Check disk space**: Ensure sufficient space on SD card (16GB+ recommended)

**Problem**: Permission errors during testing

- **Use sudo for hardware tests**: RGB and some sensor tests require root access
- **Check user groups**: Add pi user to gpio, i2c, spi groups
- **Verify device permissions**: Check /dev/ device file permissions

## 2. Wi-Fi Issues

When your Raspberry Pi cannot connect to a known Wi-Fi network (e.g., you’ve moved locations or changed routers), there are several methods to reconfigure Wi-Fi access. Each method has tradeoffs depending on whether you still have SSH or physical access.

### Method 1: Use Ethernet (Or if you have SSH access)

If you can connect your Raspberry Pi to an Ethernet cable:

1. Plug the Pi into a router or computer via Ethernet.
2. Check the Pi’s IP address from your router’s device list or using a network scanner like `nmap`.
3. SSH into the Pi:

   ```bash
   ssh pi@<ethernet_ip_address>
   ```

4. Launch the configuration tool:

   ```bash
   sudo raspi-config
   ```

5. Navigate to:

   ```pgsql
   System Options → Wireless LAN
   ```

6. Enter your Wi-Fi SSID and password when prompted.
7. Reboot the Pi to apply changes:
   ```bash
   sudo reboot
   ```

This is the most reliable method since you keep full SSH access throughout.

If you can't edit using raspi-config:

1. Edit the Wi-Fi configuration file:

   ```bash
   sudo nano /etc/wpa_supplicant/wpa_supplicant.conf
   ```

2. Add or update your Wi-Fi network block:

   ```bash
   country=US
   ctrl_interface=DIR=/var/run/wpa_supplicant GROUP=netdev
   update_config=1

   network={
       ssid="YourNetworkName"
       psk="YourNetworkPassword"
   }
   ```

3. Save (Ctrl+O, Enter) and exit (Ctrl+X).

4. Reboot the Pi to apply changes:

```bash
sudo reboot
```

### Method 2: Share a Hotspot with the Same Name and Password

If you can’t physically reach the Pi or connect Ethernet:

1. Create a mobile hotspot on your phone or laptop.
2. Use **the exact same SSID (network name)** and **password** as your old Wi-Fi network.
3. The Raspberry Pi will automatically reconnect to this hotspot, since it matches its saved credentials.

> 💡 This method is great for quick recovery if you forgot to update the Wi-Fi credentials before moving the Pi.

### Method 3: SD Card Method (Unreliable)

If you can’t SSH in or use Ethernet:

1. Power off the Raspberry Pi and remove the SD card.
2. Insert it into another computer.
3. Open the **boot** partition (the only visible partition on most systems).
4. Create a new file named `wpa_supplicant.conf` in the boot directory with the following contents:

   ```bash
   country=US
   ctrl_interface=DIR=/var/run/wpa_supplicant GROUP=netdev
   update_config=1

   network={
       ssid="YourNetworkName"
       psk="YourNetworkPassword"
   }
   ```

5. Save the file using **UTF-8 encoding** and ensure there are **no extra spaces or smart quotes**.
6. Safely eject the SD card and reinsert it into the Pi.
7. Boot up — the Pi will copy this configuration into `/etc/wpa_supplicant/` automatically.

> **Note:**
>
> - This method is less reliable on some OS versions (especially Raspberry Pi OS Bookworm).
> - Incorrect country codes or malformed files can cause Wi-Fi to fail entirely.
> - Always ensure you use plain text and standard quotation marks.

## Getting Additional Help

### Before Asking for Help

1. **Check this troubleshooting guide** thoroughly
2. **Search existing GitHub issues** for similar problems
3. **Collect diagnostic information** using commands above
4. **Take clear photos** of your setup if hardware-related

### Where to Get Help

- **GitHub Issues**: https://github.com/humancomputerlab/le_lamp/issues
- **Discord Community**: https://discord.gg/4hmNW3Ep
- **LeLamp Runtime Issues**: https://github.com/humancomputerlab/lelamp_runtime/issues

### What Information to Include

- **Problem description**: Clear, specific description of the issue
- **Steps to reproduce**: Exact sequence that leads to the problem
- **Error messages**: Complete error text, not screenshots of text
- **System information**: Pi model, OS version, hardware configuration
- **Photos**: Clear images of your setup for hardware issues

## Component Testing Order

When diagnosing issues, test components in this order:

1. **Power supply**: Verify voltage and current capacity
2. **Individual servos**: Test each servo separately
3. **Servo driver**: Verify communication and control
4. **Pi connectivity**: Ensure SSH and basic operation
5. **Individual sensors**: Camera, microphone, speakers separately
6. **Integrated systems**: Full lamp operation

This systematic approach helps isolate problems and avoid cascading failures.

---

**Previous**: [LeLamp Control](./5.%20LeLamp%20Control.md)

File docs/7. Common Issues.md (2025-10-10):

# LeLamp Troubleshooting Guide

This guide covers common issues encountered during LeLamp assembly and operation, with step-by-step solutions.

## Hardware Issues

### Pi Setup Problems

**Problem**: Cannot SSH into Pi

- **Check network connection**: Verify Pi is connected to WiFi
- **Verify SSH enabled**: Ensure SSH was enabled during OS setup
- **Check hostname**: Try IP address instead of hostname.local
- **Firewall issues**: Temporarily disable computer firewall for testing

**Problem**: Runtime installation fails

- **Check internet connection**: Ensure Pi has stable internet access
- **Update system**: Run `sudo apt update && sudo apt upgrade` first
- **Install uv manually**: Follow official uv installation instructions
- **Check disk space**: Ensure sufficient space on SD card (16GB+ recommended)

**Problem**: Permission errors during testing

- **Use sudo for hardware tests**: RGB and some sensor tests require root access
- **Check user groups**: Add pi user to gpio, i2c, spi groups
- **Verify device permissions**: Check /dev/ device file permissions

**Problem**: Change Wifi

- **Use Ethernet**: Connect your Pi to ethernet, ssh into it. Run `sudo ...
- **Share a hotspot with same name and password as old wifi**: ...
- **SD Card** (unreliable);

## Diagnostic Commands

### System Health Checks

```bash
# Check system resources
free -h
df -h
vcgencmd get_throttled

# Check hardware interfaces
lsusb
i2cdetect -y 1
gpio readall

# Test camera
libcamera-hello --timeout 2000

# Check audio devices
aplay -l
arecord -l
```

### Servo Diagnostics

```bash
# Find servo driver port
uv run lerobot-find-port

# Test servo connectivity
uv run -m lelamp.test.test_motors --id lelamp --port /dev/ttyUSB0

# Manual servo control (replace port)
uv run -m lelamp.control --id lelamp --port /dev/ttyUSB0
```

### Network and Software

```bash
# Check network connectivity
ping google.com
ip addr show

# Verify Python environment
which uv
uv --version
python3 --version

# Check service status
systemctl status ssh
systemctl status networking
```

## Getting Additional Help

### Before Asking for Help

1. **Check this troubleshooting guide** thoroughly
2. **Search existing GitHub issues** for similar problems
3. **Collect diagnostic information** using commands above
4. **Take clear photos** of your setup if hardware-related

### Where to Get Help

- **GitHub Issues**: https://github.com/humancomputerlab/le_lamp/issues
- **Discord Community**: https://discord.gg/4hmNW3Ep
- **LeLamp Runtime Issues**: https://github.com/humancomputerlab/lelamp_runtime/issues

### What Information to Include

- **Problem description**: Clear, specific description of the issue
- **Steps to reproduce**: Exact sequence that leads to the problem
- **Error messages**: Complete error text, not screenshots of text
- **System information**: Pi model, OS version, hardware configuration
- **Photos**: Clear images of your setup for hardware issues

## Component Testing Order

When diagnosing issues, test components in this order:

1. **Power supply**: Verify voltage and current capacity
2. **Individual servos**: Test each servo separately
3. **Servo driver**: Verify communication and control
4. **Pi connectivity**: Ensure SSH and basic operation
5. **Individual sensors**: Camera, microphone, speakers separately
6. **Integrated systems**: Full lamp operation

This systematic approach helps isolate problems and avoid cascading failures.

---

**Previous**: [LeLamp Control](./6.%20LeLamp%20Control.md)

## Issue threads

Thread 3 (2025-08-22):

Supplier Link of Servo Driver not valid

shark526, 2025-08-22:
hello,  seems the link not work, could you update?
https://www.alibaba.com/pla/Serial-Bus-Servo-Driver-Board-Integrates_1600997533603.html
pn bom doc: https://github.com/humancomputerlab/LeLamp/blob/master/docs/0.%20Prerequisites.md#bill-of-materials

thanks

Closed 2025-08-26.

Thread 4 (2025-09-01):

Connection issue inquiry

xiao654, 2025-09-01:
The connection between the ReSpeaker 2-Mics Pi HAT and the Raspberry Pi Zero 2 W is unclear. Could you please add a few photos of the physical connections of the entire hardware setup? Also, regarding the 5V input, is it possible to eliminate the step-down module?

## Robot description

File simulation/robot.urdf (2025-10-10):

<?xml version="1.0" ?>
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
<robot name="simulation">
  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
  <link name="lamparm__base_elbow">
    <inertial>
      <origin xyz="0.0729066 -0.0229022 0.217607" rpy="0 0 0"/>
      <mass value="0.234138"/>
      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
    </inertial>
    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
  </link>
  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
  <link name="lamparm__wrist_head">
    <inertial>
      <origin xyz="0.0193636 0.000541554 -0.0196637" rpy="0 0 0"/>
      <mass value="0.0953804"/>
      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
    </inertial>
    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
  </link>
  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
  <link name="scs215_v5">
    <inertial>
      <origin xyz="0.00584437 0.00206639 -0.0244202" rpy="0 0 0"/>
      <mass value="0.41735"/>
      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
    </inertial>
    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
  </link>
  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
  <link name="imu_site">
    <origin xyz="0 0 0" rpy="0 -0 0"/>
    <inertial>
      <origin xyz="0 0 0" rpy="0 0 0"/>
      <mass value="1e-9"/>
      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
    </inertial>
  </link>
  <joint name="imu_site_frame" type="fixed">
    <origin xyz="-3.4944e-17 4.02192e-17 -0.0378" rpy="3.14159 -5.41191e-15 1.87944"/>
    <parent link="scs215_v5"/>
    <child link="imu_site"/>
    <axis xyz="0 0 0"/>
  </joint>
  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
  <joint name="1" type="revolute">
    <origin xyz="0.04111 7.30741e-16 -0.0192" rpy="-1.5708 5.39003e-15 1.5708"/>
    <parent link="lamparm__wrist_head"/>
    <child link="scs215_v5"/>
    <axis xyz="0 0 1"/>
    <limit effort="10" velocity="10" lower="-5.02103" upper="1.26215"/>
  </joint>
  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
  <joint name="2" type="revolute">
    <origin xyz="0.00583234 0.0182927 0.08291" rpy="-1.26215 1.5708 0"/>
    <parent link="lamparm__base_elbow"/>
    <child link="lamparm__wrist_head"/>
    <axis xyz="0 0 1"/>
    <limit effort="10" velocity="10" lower="-1.08426" upper="2.05734"/>
  </joint>
  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
  <link name="lamparm__elbow_wrist">
    <inertial>
      <origin xyz="-0.00212937 0.119295 0.0220282" rpy="0 0 0"/>
      <mass value="0.206448"/>
      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
    </inertial>
    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
  </link>
  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
  <link name="lamparm__wrist_head_2">
    <inertial>
      <origin xyz="0.000541554 -0.000463734 -0.0217464" rpy="0 0 0"/>
      <mass value="0.0953804"/>
      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
    </inertial>
    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
  </link>
  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
  <link name="diffuser">
    <inertial>
      <origin xyz="-0.0641891 0.0560099 0.0186249" rpy="0 0 0"/>
      <mass value="0.0933113"/>
      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
    </inertial>
    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
  </link>
  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
  <joint name="5" type="revolute">
    <origin xyz="1.58207e-15 0.0192 -0.04111" rpy="1.5708 -1.5708 0"/>
    <parent link="lamparm__wrist_head_2"/>
    <child link="diffuser"/>
    <axis xyz="0 0 1"/>
    <limit effort="10" velocity="10" lower="-0.853337" upper="2.28826"/>
  </joint>
  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
  <joint name="4" type="revolute">
    <origin xyz="2.55351e-15 0.185185 0.006125" rpy="1.5708 -0.644947 2.92255e-15"/>
    <parent link="lamparm__elbow_wrist"/>
    <child link="lamparm__wrist_head_2"/>
    <axis xyz="0 0 1"/>
    <limit effort="10" velocity="10" lower="-3.78654" upper="2.49665"/>
  </joint>
  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
  <joint name="3" type="revolute">
    <origin xyz="0.105806 -0.0129789 0.301237" rpy="1.5708 -1.54809 -0.308645"/>
    <parent link="lamparm__base_elbow"/>
    <child link="lamparm__elbow_wrist"/>
    <axis xyz="0 0 1"/>
    <limit effort="10" velocity="10" lower="-2.82002" upper="0.321569"/>
  </joint>
  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
  <sensor>
    <accelerometer name="accel_sensor" site="imu_site"/>
    <gyro name="gyro_sensor" site="imu_site"/>
  </sensor>
  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
  <default>
    <default class="sts3215">
      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
      <joint damping="0.60" frictionloss="0.052" armature="0.028"/>
      <position kp="17.8" kv="0.0" forcerange="-3.35 3.35"/>
    </default>
    <default class="backlash">
      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
      <joint damping="0.01" frictionloss="0" armature="0.01" limited="true" range="-0.008726646259971648 0.008726646259971648"/>
    </default>
  </default>
</robot>

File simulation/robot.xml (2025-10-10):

<?xml version="1.0" ?>
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
<mujoco model="simulation">
  <compiler angle="radian" meshdir="assets" autolimits="true"/>
  <default>
    <default class="simulation">
      <joint frictionloss="0.1" armature="0.005"/>
      <position kp="50" dampratio="1"/>
      <default class="visual">
        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
      </default>
      <default class="collision">
        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
      </default>
    </default>
  </default>
  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
  <sensor>
    <accelerometer name="accel_sensor" site="imu_site"/>
    <gyro name="gyro_sensor" site="imu_site"/>
  </sensor>
  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
  <default>
    <default class="sts3215">
      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
      <joint damping="0.60" frictionloss="0.052" armature="0.028"/>
      <position kp="17.8" kv="0.0" forcerange="-3.35 3.35"/>
    </default>
    <default class="backlash">
      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
      <joint damping="0.01" frictionloss="0" armature="0.01" limited="true" range="-0.008726646259971648 0.008726646259971648"/>
    </default>
  </default>
  <worldbody>
    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
    <body name="lamparm__base_elbow" pos="0 0 0" quat="1 0 0 0" childclass="simulation">
      <freejoint name="lamparm__base_elbow_freejoint"/>
      <inertial pos="0.0729066 -0.0229022 0.217607" mass="0.234138" fullinertia="0.0010919 0.00129476 0.000320305 7.35843e-05 -0.000504692 0.000161616"/>
      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
      <body name="lamparm__wrist_head" pos="0.00583234 0.0182927 0.08291" quat="0.570913 -0.417203 0.570913 0.417203">
        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
        <joint axis="0 0 1" name="2" type="hinge" range="-1.0842575396713956 2.0573351139183975" class="sts3215"/>
        <inertial pos="0.0193636 0.000541554 -0.0196637" mass="0.0953804" fullinertia="1.16713e-05 2.19256e-05 1.7794e-05 -3.19269e-07 9.361e-07 6.98105e-08"/>
        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
        <body name="scs215_v5" pos="0.04111 7.30741e-16 -0.0192" quat="0.5 -0.5 -0.5 0.5">
          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
          <joint axis="0 0 1" name="1" type="hinge" range="-5.021033992714066 1.2621513144655205" class="sts3215"/>
          <inertial pos="0.00584437 0.00206639 -0.0244202" mass="0.41735" fullinertia="0.00100304 0.00122902 0.00205034 -8.49257e-05 -8.64397e-06 -3.34823e-06"/>
          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
        </body>
      </body>
      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
      <body name="lamparm__elbow_wrist" pos="0.105806 -0.0129789 0.301237" quat="0.575614 0.423658 -0.566139 0.410693">
        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
        <joint axis="0 0 1" name="3" type="hinge" range="-2.820024081304335 0.3215685722854582" class="sts3215"/>
        <inertial pos="-0.00212937 0.119295 0.0220282" mass="0.206448" fullinertia="0.000632713 4.80236e-05 0.000602863 -1.84707e-05 -1.72868e-06 -1.49987e-05"/>
        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
        <body name="lamparm__wrist_head_2" pos="2.55351e-15 0.185185 0.006125" quat="0.670659 0.670659 -0.224092 0.224092">
          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
          <joint axis="0 0 1" name="4" type="hinge" range="-3.7865399953934267 2.4966453117861596" class="sts3215"/>
          <inertial pos="0.000541554 -0.000463734 -0.0217464" mass="0.0953804" fullinertia="2.19256e-05 1.7794e-05 1.16713e-05 6.98105e-08 -3.19269e-07 9.361e-07"/>
          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
          <body name="diffuser" pos="1.58207e-15 0.0192 -0.04111" quat="0.5 0.5 -0.5 0.5">
            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
            <joint axis="0 0 1" name="5" type="hinge" range="-0.8533371981959901 2.288255455393803" class="sts3215"/>
            <inertial pos="-0.0641891 0.0560099 0.0186249" mass="0.0933113" fullinertia="0.000164418 0.000170062 0.000206169 2.06383e-05 7.21792e-11 4.01082e-10"/>
            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
          </body>
        </body>
      </body>
    </body>
  </worldbody>
  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
  <actuator>
    <position class="sts3215" name="2" joint="2" inheritrange="1"/>
    <position class="sts3215" name="1" joint="1" inheritrange="1"/>
    <position class="sts3215" name="3" joint="3" inheritrange="1"/>
    <position class="sts3215" name="4" joint="4" inheritrange="1"/>
    <position class="sts3215" name="5" joint="5" inheritrange="1"/>
  </actuator>
  <equality/>
</mujoco>

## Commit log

2025-10-10 Update documentation
    [Diffuser.3mf, Lamp Base (Rectangle).3mf, Lamp Base Cover.3mf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]
2025-10-10 Fix simulation
    [diffuser.stl, ge_27.stl, lamp_base.stl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]
2025-10-13 Fix 3d models
    [LampArm (Elbow-Wrist).3mf, LampHead - Diffuser.3mf]
